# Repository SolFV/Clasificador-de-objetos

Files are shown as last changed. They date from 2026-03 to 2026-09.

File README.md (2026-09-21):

# 🏭 Clasificador Automático de Cajas con Visión Artificial
### Proyecto 4: Interfaz de Usuario y Estructura Mecánica de Cinta Transportadora

<div align="center">








**Sistema mecatrónico embebido de inspección de calidad y clasificación automatizada de paquetes sobre cinta transportadora, integrando visión artificial en la nube, tracción controlada por motor paso a paso, almacenamiento de evidencias y dashboard de supervisión en tiempo real.**

*Facultad de Ingeniería — Universidad Nacional de Asunción (FIUNA)*  
*Cátedra: Proyecto 4 (2do Ciclo 2026) | Septiembre de 2026*  
*Profesores: Prof. Ing. Federico Gaona, MSc. (Teoría) — Prof. Ing. Esteban Fretes, MSc. (Práctica)*

</div>

---

## 📋 Tabla de Contenidos

- [Descripción General](#-descripción-general)
- [Estado del Proyecto — Hitos del 1er Parcial](#-estado-del-proyecto--hitos-del-1er-parcial)
- [Esquema General del Sistema](#-esquema-general-del-sistema)
- [Arquitectura de Hardware](#️-arquitectura-de-hardware)
  - [1. Subsistema Mecánico y Estructura (SolidWorks)](#1-subsistema-mecánico-y-estructura-solidworks)
  - [2. Subsistema de Tracción (NEMA 23 + L298N)](#2-subsistema-de-tracción-nema-23--l298n)
  - [3. Subsistema Electrónico de Control (PCB ESP32-S3)](#3-subsistema-electrónico-de-control-pcb-esp32-s3)
- [Flujo de Operación y Lógica de Clasificación](#-flujo-de-operación-y-lógica-de-clasificación)
- [Infraestructura IoT y Servidor de Visión (n8n)](#-infraestructura-iot-y-servidor-de-visión-n8n)
- [Interfaz de Usuario (Dashboard de Supervisión)](#-interfaz-de-usuario-dashboard-de-supervisión)
- [Resultados Experimentales del Parcial](#-resultados-experimentales-del-parcial)
- [Costos del Proyecto](#-costos-del-proyecto)
- [Estructura del Repositorio](#-estructura-del-repositorio)
- [Autores y Agradecimientos](#-autores-fiuna--2026)
- [Licencia](#-licencia)

---

## 📖 Descripción General

El proyecto resuelve el **control de calidad en líneas de empaquetado** mediante un prototipo mecatrónico accesible y modular: una cinta transportadora desplaza cajas frente a una estación de inspección óptica (sensor infrarrojo de proximidad y cámara digital), un agente de visión artificial dictamina el estado del empaque y el sistema registra la evidencia fotográfica en la nube a la vez que acciona un mecanismo deflector para separar los productos defectuosos.

El alcance del **Primer Parcial del Proyecto 4** cierra la brecha entre la electrónica fabricada previamente en el Proyecto 3 y la operación física en planta, dotando al clasificador de:
1. **Estructura mecánica formal:** Chasis, rodillos, banda de caucho y soportes diseñados en SolidWorks con planos constructivos acotados.
2. **Tracción precisa con motor paso a paso:** Sustitución del motor DC de tracción por un motor paso a paso **NEMA 23** con controlador dedicado **L298N**, logrando un avance controlado con paradas repetibles de **1,2 s** frente a la cámara para eliminar el desenfoque por movimiento (*motion blur*).
3. **Pipeline de visión en la nube:** Servidor autoalojado **n8n** que procesa la imagen con **OpenAI `gpt-4o-mini`**, almacena evidencias en **Google Drive** y registros numéricos en **Google Sheets**.
4. **Dashboard web en tiempo real:** Interfaz de supervisión que lee la hoja de resultados cada 10 segundos, mostrando métricas, miniaturas de las cajas inspeccionadas y exportación a CSV.

---

## ✅ Estado del Proyecto — Hitos del 1er Parcial

> **El Primer Parcial del Proyecto 4 ha sido completado y validado experimentalmente con éxito en laboratorio.**

### Matriz de Hitos (P4 — Primer Parcial):

| Hito / Entregable | Estado | Observación |
| :--- | :---: | :--- |
| **Diseño mecánico en SolidWorks (CAD 3D)** | ✅ Completado | Modelos de bastidor, rodillos, engranajes y ensamble completo (`Ensamble.SLDASM`). |
| **Planos técnicos acotados de fabricación** | ✅ Completado | Planos 2D en PDF de engranaje conductor, conducido, soporte lateral y ensamble general. |
| **Tracción paso a paso NEMA 23 + L298N** | ✅ Completado | Paradas programadas de 1,2 s y avance exacto sin deslizamiento. |
| **Transmisión por engranajes rectos (3.8:1)** | ✅ Completado | Impresión 3D en PLA de piñón (z=10) y corona (z=38), módulo 4 mm. |
| **Flujo de Visión n8n + GPT-4o-mini** | ✅ Completado | Inferencia visual remota con latencia de 2,5 a 4,0 s. |
| **Registro Cloud (Google Drive + Sheets)** | ✅ Completado | Almacenamiento automático de fotos y fila de metadatos por evento. |
| **Dashboard Web de Supervisión** | ✅ Completado | Actualización continua cada 10 s, KPIs por estado, visor fotográfico y exportación CSV. |
| **Ensamble y validación del prototipo físico** | ✅ Completado | Estructura de contrachapado y varillas DIN 975 operativa y verificada en banco. |

---

## 🗺️ Esquema General del Sistema

El sistema opera mediante la interacción coordinada de cinco bloques funcionales:

```
                  +-------------------------------------------------------------+
                  |                      UNIDAD DE CONTROL                      |
                  |                Placa Propia ESP32-S3 (3.3V)                 |
                  +--------------+------------------------------+---------------+
                                 |                              |
               Señal de Detención|                              |Control de Desvío
               y Pulsos de Avance|                              |Pulsos PWM (0° / 180°)
                                 v                              v
            +--------------------+---------+          +---------+--------------------+
            |      SUBSISTEMA TRACCIÓN     |          |       SUBSISTEMA DESVÍO      |
            |     Driver L298N + NEMA 23   |          |    Servomotor SER0006        |
            |  Engranajes PLA (Red. 3.8:1) |          | Brazo Deflector (20s retenc.)|
            +--------------------+---------+          +------------------------------+
                                 |
                                 v
                     [ Cinta Transportadora ] <=== [ Cajas en Tránsito ]
                                 |
                          Detección IR (E18-D80NK)
                          Captura Foto (OV5640 SVGA)
                                 |
                                 v WiFi (HTTP POST Webhook)
            +--------------------+---------------------------------------------------+
            |                     SERVIDOR DE VISIÓN (n8n Autoalojado)               |
            |             Agente IA de Visión (OpenAI gpt-4o-mini)                  |
            +--------------------+------------------------------+--------------------+
                                 |                              |
                   Guarda Foto   v                 Guarda Fila  v
                         +-------+-------+              +-------+-------+
                         | Google Drive  |              | Google Sheets |
                         +-------+-------+              +-------+-------+
                                 |                              |
                                 |            Lectura cada 10 s |
                                 +--------------+---------------+
                                                v
                                 +--------------+---------------+
                                 |     DASHBOARD WEB (GUI)      |
                                 |  Supervisión en Tiempo Real  |
                                 +------------------------------+
```

---

## 🛠️ Arquitectura de Hardware

### 1. Subsistema Mecánico y Estructura (SolidWorks)
La cinta transportadora se diseñó íntegramente en SolidWorks bajo criterios de rigidez, repetibilidad y desmontaje modular:
- **Bastidor Lateral (`Tabla.SLDPRT` / [Soporte Lateral.pdf](Hardware/Diseno_Mecanico/Soporte%20Lateral.pdf)):** 2 placas de madera contrachapada de $700 \times 150\text{ mm}$ y $12\text{ mm}$ de espesor con perforaciones para varillas y rodamientos.
- **Tirantes Transversales (`Varilla.SLDPRT`):** 7 varillas roscadas de acero al carbono galvanizado bajo norma **DIN 975** (M6), aportando alta rigidez torsional.
- **Banda de Transporte (`Cinta.SLDPRT`):** Banda cerrada de caucho continuo con ancho útil de **200 mm**, compatible con cajas de hasta 150 mm.
- **Transmisión por Engranajes Rectos en PLA (Módulo 4 mm):**
  - **Engranaje Conductor (`Engranaje_C.SLDPRT` / [Engranaje_Conductor.pdf](Hardware/Diseno_Mecanico/Engranaje_Conductor.pdf)):** $z_1 = 10\text{ dientes}$, diámetro exterior $\varnothing 48.00\text{ mm}$, acople a eje del motor NEMA 23 de $\varnothing 8.00\text{ mm}$.
  - **Engranaje Conducido (`engranaje_G.SLDPRT` / [engranaje_conducido.PDF](Hardware/Diseno_Mecanico/engranaje_conducido.PDF)):** $z_2 = 38\text{ dientes}$, diámetro exterior $\varnothing 160.00\text{ mm}$, acople a eje motriz de $\varnothing 6.00\text{ mm}$.
  - **Relación de Reducción:** $i = 3.8:1$, cuadruplicando el par sobre el rodillo motriz y permitiendo una resolución de avance lineal de $\approx 0.165\text{ mm/paso}$.
- **Planos Técnicos:** Disponibles en [Hardware/Diseno_Mecanico/](Hardware/Diseno_Mecanico/) con el ensamble general en [Cinta transportadora.pdf](Hardware/Diseno_Mecanico/Cinta%20transportadora.pdf) y el informe técnico detallado en [Informe_Diseno_Estructural_Mecanico.md](Hardware/Diseno_Mecanico/Informe_Diseno_Estructural_Mecanico.md).

### 2. Subsistema de Tracción (NEMA 23 + L298N)
- **Motor:** Paso a paso híbrido bipolar NEMA 23 (**modelo 23HS5628**), ángulo de paso $1.8^\circ$ (200 pasos/rev) y torque nominal de **12.6 kgf-cm** (1.23 N·m).
- **Controlador:** Driver tipo puente H bipolar **L298N**, alimentado desde una línea de potencia externa dedicada y comandado por señales lógicas de 3.3V desde la placa ESP32-S3.

### 3. Subsistema Electrónico de Control (PCB ESP32-S3)
Se reutiliza la placa desarrollada y validada en el Proyecto 3 (alojada en [Hardware/Diseño final p3/](Hardware/Diseño%20final%20p3/)):
- **Microcontrolador:** ESP32-S3-WROOM-1-N16R8 (Dual-core 240 MHz, 16 MB Flash, 8 MB PSRAM verificada).
- **Cámara Óptica:** Módulo digital Omnivision **OV5640** conectado mediante interfaz de video en paralelo DVP (resolución de trabajo SVGA $800 \times 600$).
- **Sensor de Presencia:** Sensor fotoeléctrico infrarrojo **E18-D80NK** enfocado a la zona de captura (tiempo de respuesta $< 50\text{ ms}$).
- **Actuador de Desvío:** Servomotor **DFRobot SER0006** montado con brazo deflector mecánico a la salida del tramo de inspección.

---

## 🔄 Flujo de Operación y Lógica de Clasificación

El lazo de control opera de acuerdo a la siguiente secuencia automática:

1. **Avance Continuo:** El motor NEMA 23 hace avanzar la cinta transportadora de manera uniforme.
2. **Detección Frontal:** El sensor infrarrojo E18-D80NK detecta la llegada del paquete e interrumpe el avance.
3. **Parada y Captura:** La cinta se detiene exactamente durante **1,2 segundos**. La cámara OV5640 toma una fotografía nítida en SVGA almacenándola en la PSRAM.
4. **Transmisión IoT:** El ESP32-S3 envía la imagen por WiFi al webhook de n8n mediante HTTP POST.
5. **Inferencia Visual:** El agente de IA (`gpt-4o-mini`) analiza la morfología y condiciones del empaque, dictaminando la categoría:
   - 🟢 **Verde (Buen Estado):** Caja intacta, correctamente sellada y lista para despacho.
   - 🟡 **Amarillo (Sin Caja o No Empaque):** Falsa alarma, objeto extraño o cinta vacía.
   - 🔴 **Rojo (Caja Dañada):** Paquete aplastado, roto, perforado o con defectos visibles.
6. **Almacenamiento Cloud:** El flujo guarda la imagen en una carpeta compartida de **Google Drive** y registra una nueva fila en **Google Sheets** con timestamp, color y descripción detallada.
7. **Acción del Servomotor:** El ESP32-S3 recibe la respuesta `[{color, descripcion}]` y ejecuta la maniobra:
   - 🟢 **Verde:** El brazo deflector permanece a **0°** (la caja continúa sin desvío).
   - 🟡 / 🔴 **Amarillo o Rojo:** El servomotor gira a **180°** y mantiene la posición de desvío durante **20 segundos** para enviar la pieza a la bandeja de rechazo.
8. **Reanudación:** El servomotor retorna a posición neutra (0°) y la cinta reanuda la marcha.

---

## 🤖 Infraestructura IoT y Servidor de Visión (n8n)

El procesamiento cognitivo se delega íntegramente a un servidor local **n8n autoalojado** (*Workflow Proyecto 4*):

```
[Webhook HTTP] ──▶ [Recibir imagen y Nombrar] ──▶ [Base64 a Binario] ──▶ [AI Agent (gpt-4o-mini)]
                                                                                │
[Responder al Webhook: {color, desc}] ◀── [Limpiar Output Agente] ◀─────────────┘
          │
          ├──▶ [Subir a Google Drive]
          └──▶ [Subir a Google Sheets]
```

- **Modelo de Inferencia:** OpenAI `gpt-4o-mini` configurado con *system prompt* especializado en control de calidad industrial.
- **Respuesta JSON:** Formato estandarizado `[ { "color": "verde" | "amarillo" | "rojo", "descripcion": "..." } ]`.
- **Ventaja de la Arquitectura:** Libera al microcontrolador de tareas pesadas de redes neuronales, acelerando la toma de decisiones ($2.5 - 4.0\text{ s}$).

---

## 🖥️ Interfaz de Usuario (Dashboard de Supervisión)

El monitoreo del sistema se realiza a través de un **Dashboard Web en Tiempo Real** de un solo archivo:
- **Consulta Automática:** Sondea la planilla de Google Sheets (*Proyecto4 - Hoja 1*) cada **10 segundos**.
- **Panel de KPIs:** Conteo total de cajas evaluadas, desglose por categoría (verde, amarillo, rojo) y cálculo porcentual.
- **Tarjeta de Última Detección:** Muestra la fotografía en miniatura cargada desde Google Drive, el estado asignado, la descripción diagnóstica de la IA y el ángulo/tiempo aplicado por el servomotor.
- **Historial y Exportación:** Tabla con las últimas 5 detecciones en vivo y botón para exportar todo el registro histórico acumulado a formato **CSV**.
- **Accesos Directos:** Enlaces directos a la planilla en línea y a la carpeta de evidencias en Drive.
- **Modo Seguro:** Opera en modo solo lectura para supervisión remota sin interferir en la máquina de estados del firmware.

---

## 📊 Resultados Experimentales del Parcial

Durante las pruebas funcionales del prototipo integrado se validaron las siguientes métricas de desempeño:

| Parámetro Operativo | Valor Medido | Valor Esperado / Criterio |
| :--- | :---: | :---: |
| **Tiempo de parada de cinta frente a cámara** | **1,2 s** | Repetible, sin desenfoque de imagen |
| **Latencia de detección del sensor IR** | **< 50 ms** | Detención instantánea del NEMA 23 |
| **Tiempo de respuesta inferencia n8n** | **2,5 a 4,0 s** | Dentro del ciclo de cinta previsto |
| **Retención del servomotor en rechazo (180°)** | **20 s** | Desvío seguro al contenedor de descarte |
| **Frecuencia de actualización del Dashboard** | **10 s** | Supervisión fluida de métricas Cloud |
| **Resolución cinemática de la cinta** | **~0,165 mm/paso** | Posicionamiento milimétrico repetible |

---

## 💰 Costos del Proyecto

La estructura de costos del prototipo se basa en una tasa oficial de referencia de **1 USD = 6.391 Gs.**:

### 1. Materiales y Herramientas Compradas (Incorporadas al Proyecto 4)

| Descripción / Componente | MPN / Modelo | Cant. | Unitario (USD) | Total (USD) | Total (Gs.) |
| :--- | :--- | :---: | :---: | :---: | :---: |
| **Motor paso a paso NEMA 23 (12.6 kgf-cm)** | 23HS5628 | 1 | 46,94 | 46,94 | 300.000 |
| **Microcontrolador ESP32-S3** | ESP32-S3-WROOM-1-N16R8 | 2 | 8,72 | 17,44 | 111.459 |
| **Módulo de cámara OV5640** | 5840 (Adafruit) | 1 | 9,95 | 9,95 | 63.590 |
| **Capacitor electrolítico 100 uF** | EEE-FK1H101P | 6 | 0,76 | 4,56 | 29.143 |
| **Servomotor 180°** | SER0006 | 1 | 3,63 | 3,63 | 23.199 |
| **Capacitor cerámico 4,7 uF 0805** | CL21B475KOFNNNE | 6 | 0,25 | 1,50 | 9.587 |
| **Diodo Schottky 40 V, 1 A** | SS14F-HF | 4 | 0,32 | 1,28 | 8.180 |
| **Conector USB tipo C hembra** | USB4510-03-1-A | 1 | 0,84 | 0,84 | 5.368 |
| **Capacitor cerámico 10 uF 0805** | CL21B106KOQNNNE | 6 | 0,14 | 0,84 | 5.368 |
| **Capacitor cerámico 22 uF 0805** | CL21A226MQQNNNE | 6 | 0,13 | 0,78 | 4.985 |
| **Resistencia 15 kOhm 0805** | RC0805FR-0715KL | 6 | 0,13 | 0,78 | 4.985 |
| **Capacitor cerámico 2,2 uF 0805** | CL21B225KOFNNNE | 6 | 0,12 | 0,72 | 4.602 |
| **Regulador LDO 3,3 V** | LD1117S33TR | 2 | 0,34 | 0,68 | 4.346 |
| **Resistencia 10 kOhm 0805** | RC0805FR-0710KL | 6 | 0,11 | 0,66 | 4.218 |
| **Capacitores y Resistencias SMD 0805 varios** | Pasivos estándar | — | — | 6,14 | 39.299 |
| **SUBTOTAL COMPONENTES COMPRADOS** | — | — | — | **$96,06** | **644.219 Gs.** |

> *Costo por integrante (3 personas): **$32.02 USD (214.740 Gs.)**.*  
> El desglose línea a línea con enlaces y números de parte se encuentra en el archivo [BOM.csv](BOM.csv).

### 2. Materiales y Herramientas Preexistentes o Prestadas (Sin costo incremental)

| Descripción | Cantidad | Observaciones / Procedencia |
| :--- | :---: | :--- |
| **Placa propia ESP32-S3 con cámara OV5640** | 1 | Fabricada y validada en Proyecto 3 |
| **Servomotor de desvío SER0006** | 1 | Reutilizado de la etapa previa |
| **Controlador L298N para motor paso a paso** | 1 | Driver provisto para tracción |
| **Notebook con servidor n8n autoalojado** | 1 | Estación de inferencia local |
| **Licencia / estación SolidWorks CAD** | 1 | Laboratorio FIUNA |
| **Multímetro y herramientas de banco/taller** | 1 | Instrumental de ensamblaje y prueba |

---

## 📁 Estructura del Repositorio

```
📦 Clasificador de Objetos/
├── 📂 Hardware/                                # Proyectos de diseño físico y electrónico
│   ├── 📂 Diseno_Mecanico/                     # Diseño mecánico CAD y planos (P4)
│   │   ├── 📄 Informe_Diseno_Estructural_Mecanico.md # Informe técnico mecánico detallado
│   │   ├── 📄 Cinta transportadora.pdf         # Plano de ensamble general, despiece y lista de partes
│   │   ├── 📄 Soporte Lateral.pdf              # Plano acotado de soporte lateral de madera contrachapada
│   │   ├── 📄 Engranaje_Conductor.pdf          # Plano acotado de engranaje conductor (z=10, m=4)
│   │   ├── 📄 engranaje_conducido.PDF          # Plano acotado de engranaje conducido (z=38, m=4)
│   │   ├── 🧊 Ensamble.SLDASM                  # Ensamblaje 3D general en SolidWorks
│   │   ├── 🧊 Cinta.SLDPRT                     # Modelo 3D de la banda transportadora
│   │   ├── 🧊 Engranaje_C.SLDPRT               # Modelo 3D de engranaje conductor (PLA)
│   │   ├── 🧊 engranaje_G.SLDPRT               # Modelo 3D de engranaje conducido (PLA)
│   │   ├── 🧊 Tabla.SLDPRT                     # Modelo 3D de soporte lateral
│   │   ├── 🧊 Varilla.SLDPRT                   # Modelo 3D de varilla roscada DIN 975
│   │   └── 🧊 nema23.SLDPRT                    # Modelo 3D de motor paso a paso NEMA 23
│   ├── 📂 Componentes/                         # Bibliotecas KiCad personalizadas
│   ├── 📂 Diseño final p3/                     # Proyecto final KiCad de la PCB (Proyecto 3)
│   │   └── 📂 Grupo15/                         # Esquemático, ruteado, producción y Gerbers
│   ├── 📂 ESP32_S3_WROOM2_N32R16_29/           # Footprint y símbolo de la MCU
│   ├── 🖼️ Diseño.jpeg                          # Esquemático general del circuito
│   ├── 🖼️ pcb_ruteado.PNG                       # Ruteado y layout de 2 capas
│   ├── 🖼️ pcb_3d.PNG                           # Render 3D superior de la PCB
│   ├── 🖼️ pcb_3d_1.png                         # Render 3D superior sin componentes
│   └── 🖼️ pcb_3d_vistinferior.png              # Render 3D inferior de la PCB
├── 📂 Software/                                # Firmware y aplicaciones de control
│   ├── 📄 P3_2P_code.txt                       # Firmware C++/Arduino para ESP32-S3
│   ├── 📂 SnapshotP4.0/                        # Aplicación Android para inspección
│   │   └── 📱 Cinta IA.apk                     # Instalador ejecutable Android
│   └── 📂 Pruebas/                             # Scripts de validación de cámara y PSRAM
├── 📄 BOM.csv                                  # Lista de materiales y costos actualizada (USD / Gs.)
├── 📄 Informe_finalP3.pdf                      # Informe oficial completo del Proyecto 3
├── 📄 Cronograma de actividades P4.pdf         # Cronograma oficial de la Etapa P4 (PDF)
├── 📊 Cronograma de actividades.xlsx           # Planilla Excel de seguimiento
├── 🖼️ DiagramadeGantt.png                     # Diagrama de Gantt oficial
├── 🖼️ diagrama-flujo.png                       # Diagrama de flujo general del sistema
├── 📄 LICENSE                                  # Licencia de código abierto MIT
└── 📄 README.md                                # Documentación principal del repositorio
```

---

## 👥 Autores (FIUNA — 2026)

* **José Fabián Medina Dávalos** — [jfmedina@fiuna.edu.py](mailto:jfmedina@fiuna.edu.py)
* **Sol Aramí Fernández Vargas** — [solfernandez@fiuna.edu.py](mailto:solfernandez@fiuna.edu.py)
* **Gabriela Belén Orrego Arzamendia** — [gorrego@fiuna.edu.py](mailto:gorrego@fiuna.edu.py)

**Facultad de Ingeniería — Universidad Nacional de Asunción (FIUNA)**  
*Cátedra de Proyecto 4 — Carrera de Ingeniería Mecatrónica*  
*Docentes:* Prof. Ing. Federico Gaona, MSc. (Teoría) & Prof. Ing. Esteban Fretes, MSc. (Práctica)

---

## 📄 Licencia

Este proyecto está distribuido bajo la **Licencia MIT**. Para más detalles, consulte el archivo [LICENSE](LICENSE).

---

<div align="center">

*Clasificador Automático de Cajas con Visión Artificial — FIUNA — 2026*

</div>

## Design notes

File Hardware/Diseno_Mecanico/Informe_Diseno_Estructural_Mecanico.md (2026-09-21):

# 📐 Informe Técnico: Diseño Estructural y Mecánico de la Cinta Transportadora
**Proyecto 4 — Clasificador Automático de Cajas con Visión Artificial: Interfaz de Usuario y Estructura Mecánica de Cinta Transportadora**  
*Facultad de Ingeniería — Universidad Nacional de Asunción (FIUNA)*  
*Cátedra: Proyecto 4 (2do Ciclo 2026) | Profesores: Prof. Ing. Federico Gaona, MSc. — Prof. Ing. Esteban Fretes, MSc.*  
*Autores: José Fabián Medina Dávalos, Sol Aramí Fernández Vargas, Gabriela Belén Orrego Arzamendia*

---

## 1. 📌 Descripción General y Alcance del Diseño Mecánico

El presente informe técnico describe la arquitectura estructural, componentes de ensamble, cálculos cinemáticos y planos de fabricación del sistema mecánico de la cinta transportadora del **Proyecto 4 (Primer Parcial)**.

En esta etapa, el sistema sustituye el accionamiento previo por motor DC por un **motor paso a paso NEMA 23 (23HS5628)** acoplado mediante un par de engranajes rectos de reducción diseñados en **SolidWorks**. Esta solución garantiza un avance controlado, repetible y con paradas programadas de **1,2 s** frente a la estación de inspección óptica (cámara OV5640 y sensor infrarrojo E18-D80NK), suprimiendo cualquier desenfoque por movimiento (*motion blur*) durante la captura de imágenes.

```
+-----------------------------------------------------------------------------------------+
|                                ESTRUCTURA MECÁNICA GENERAL                              |
|                                                                                         |
|  [ Motor NEMA 23 ]                                                                      |
|        |                                                                                |
|  [ Engranaje Conductor (z=10, m=4) ]                                                    |
|        | (Reducción 3.8:1)                                                              |
|  [ Engranaje Conducido (z=38, m=4) ]                                                    |
|        |                                                                                |
|  [ Eje y Rodillo Motriz ] ======> [ Banda de Caucho (200 mm) ] ======> [ Rodillo Tensor ]
|                                    (Chasis: Madera Contrachapada + 7 Varillas DIN 975)  |
+-----------------------------------------------------------------------------------------+
```

---

## 2. ⚙️ Criterios de Diseño y Requerimientos Funcionales

1. **Ancho Útil de Transporte:** Banda de $200\text{ mm}$ de ancho para alojar con holgura paquetes y cajas de hasta $150\text{ mm}$.
2. **Control de Avance y Posicionamiento:** Capacidad de detener la cinta de manera instantánea y repetible al activarse el sensor IR E18-D80NK (latencia $< 50\text{ ms}$).
3. **Rigidez Torsional y Alineación:** Chasis autoportante de madera contrachapada fijado mediante varillas roscadas pasantes de acero métrico, garantizando paralelismo estricto entre ejes.
4. **Mantenimiento y Desmontaje:** Facilidad para cambiar o tensar la banda sin requerir el desarmado total del bastidor.
5. **Manufactura Híbrida y Accesible:**
   - Estructura portante en madera contrachapada mecanizada.
   - Transmisión cinemática fabricada mediante **impresión 3D (PLA)**.
   - Elementos de unión normalizados (acero DIN 975 grado comercial).

---

## 3. 🧩 Descripción de Componentes Mecánicos

### 3.1 Chasis y Laterales del Bastidor (`Tabla.SLDPRT` / `Soporte Lateral.pdf`)
- **Material:** Madera contrachapada de primera calidad de $12.00\text{ mm}$ de espesor.
- **Dimensiones Principales:** Longitud total $700.00\text{ mm}$, altura $150.00\text{ mm}$.
- **Puntos de Sujeción y Fijación:**
  - 6 perforaciones pasantes de $\varnothing 6.50\text{ mm}$ distribuidas a lo largo del soporte para las varillas roscadas estructurales (con cotas de espaciado $175.00\text{ mm}$, $350.00\text{ mm}$, etc.).
  - Alojamiento de ejes principales con orificios de $\varnothing 8.00\text{ mm}$ situados a $25.00\text{ mm}$ y $58.04\text{ mm}$ de referencias clave.
  - Guías y ranuras de ajuste para el tensado de la banda en el rodillo conducido.

### 3.2 Tirantes Estructurales Transversales (`Varilla.SLDPRT`)
- **Norma y Material:** Acero al carbono galvanizado según norma **DIN 975**.
- **Cantidad:** 7 varillas roscadas M6.
- **Función:** Unen rígidamente ambos laterales de madera contrachapada mediante tuercas y arandelas exteriores e interiores, proporcionando una estructura tipo celosía de alta resistencia a la flexión y torsión.

### 3.3 Banda Transportadora y Rodillos (`Cinta.SLDPRT`)
- **Banda:** Banda plana vulcanizada de caucho continuo con cara superior antideslizante de $200\text{ mm}$ de ancho útil.
- **Rodillos:** Cilindros concéntricos montados sobre rodamientos de bolas de bajo rozamiento para asegurar rotación suave bajo carga.

---

## 4. ⚙️ Sistema de Transmisión por Engranajes Cilíndricos Rectos

Para vincular el motor NEMA 23 al eje del rodillo motriz se diseñó una etapa reductora de engranajes de dientes rectos, modelados en SolidWorks e impresos en PLA de alta densidad de relleno.

### 4.1 Parámetros Geométricos del Engranaje Conductor (`Engranaje_C.SLDPRT` / `Engranaje_Conductor.pdf`)

| Parámetro Geométrico | Símbolo | Valor de Diseño |
| :--- | :---: | :---: |
| **Módulo** | $m$ | $4\text{ mm}$ |
| **Número de Dientes** | $z_1$ | $10$ |
| **Ángulo de Presión** | $\alpha$ | $20^\circ$ |
| **Diámetro Primitivo** | $d_{p1} = m \cdot z_1$ | $40.00\text{ mm}$ |
| **Diámetro Exterior** | $d_{e1} = d_{p1} + 2m$ | $48.00\text{ mm}$ |
| **Espesor del Diente (Ancho de Cara)** | $b_1$ | $12.00\text{ mm}$ |
| **Altura Total con Cubo** | $h_{\text{cubo}}$ | $22.00\text{ mm}$ |
| **Diámetro del Cubo** | $d_{\text{cubo}}$ | $16.00\text{ mm}$ |
| **Diámetro de Eje (Eje Motor NEMA 23)** | $d_{\text{eje1}}$ | $\varnothing 8.00\text{ mm}$ |
| **Tipo de Perfil** | — | Evolvente / Involuta estándar |
| **Material** | — | Polímero termoplástico (PLA) |

### 4.2 Parámetros Geométricos del Engranaje Conducido (`engranaje_G.SLDPRT` / `engranaje_conducido.PDF`)

| Parámetro Geométrico | Símbolo | Valor de Diseño |
| :--- | :---: | :---: |
| **Módulo** | $m$ | $4\text{ mm}$ |
| **Número de Dientes** | $z_2$ | $38$ |
| **Ángulo de Presión** | $\alpha$ | $20^\circ$ |
| **Diámetro Primitivo** | $d_{p2} = m \cdot z_2$ | $152.00\text{ mm}$ |
| **Diámetro Exterior** | $d_{e2} = d_{p2} + 2m$ | $160.00\text{ mm}$ |
| **Espesor del Diente** | $b_2$ | $12.00\text{ mm}$ |
| **Diámetro de Eje** | $d_{\text{eje2}}$ | $\varnothing 6.00\text{ mm}$ |
| **Tipo de Perfil** | — | Evolvente / Involuta estándar |
| **Material** | — | Polímero termoplástico (PLA) |

### 4.3 Relación de Reducción y Distancia Entre Centros

* **Relación de transmisión ($i$):**
  $$i = \frac{z_2}{z_1} = \frac{38}{10} = 3.8:1$$

* **Distancia teórica entre centros ($a$):**
  $$a = \frac{d_{p1} + d_{p2}}{2} = \frac{40\text{ mm} + 152\text{ mm}}{2} = \frac{192\text{ mm}}{2} = 96.00\text{ mm}$$

> **Efecto cinemático:** La relación de reducción $3.8:1$ multiplica el torque entregado al rodillo motriz por un factor de casi 4, permitiendo mover la cinta con suavidad y posicionar la caja de manera controlada frente a la cámara.

---

## 5. 🧮 Cinemática de Tracción y Parada

### 5.1 Motor Paso a Paso NEMA 23 (Modelo 23HS5628)
- **Ángulo de paso nativo:** $1.8^\circ \pm 5\%$ ($200\text{ pasos/revolución}$).
- **Torque de retención nominal:** $12.6\text{ kgf}\cdot\text{cm}$ ($1.23\text{ N}\cdot\text{m}$).
- **Controlador:** L298N (puente H bipolar).

### 5.2 Desplazamiento Lineal por Paso
Para un diámetro del rodillo motriz $D_{\text{rodillo}} \approx 40\text{ mm}$:
- Circunferencia del rodillo motriz:
  $$C_{\text{rodillo}} = \pi \cdot D_{\text{rodillo}} \approx 3.1416 \times 40\text{ mm} \approx 125.66\text{ mm}$$
- Desplazamiento lineal del rodillo motriz por revolución del motor:
  $$\Delta x_{\text{rev\_motor}} = \frac{C_{\text{rodillo}}}{i} = \frac{125.66\text{ mm}}{3.8} \approx 33.07\text{ mm/rev}$$
- Resolución de avance por paso del motor ($1.8^\circ$):
  $$\Delta x_{\text{paso}} = \frac{33.07\text{ mm}}{200\text{ pasos}} \approx 0.165\text{ mm/paso}$$

Esta precisión milimétrica ($0.165\text{ mm}$ por paso completo) garantiza que cuando el sensor fotoeléctrico infrarrojo **E18-D80NK** detecta el borde de ataque de la caja, la cinta se detiene exactamente en el centro del encuadre óptico de la cámara **OV5640**.

---

## 6. 📋 Lista de Partes y Ensamble General (`Ensamble.SLDASM` / `Cinta transportadora.pdf`)

| Ítem | N° de Parte / Nombre | Descripción y Material | Cantidad | Plano Técnico / Modelo |
| :---: | :--- | :--- | :---: | :--- |
| **1** | `Soporte Lateral` | Madera Contrachapada e = 12 mm | 2 | `Soporte Lateral.pdf` / `Tabla.SLDPRT` |
| **2** | `Varilla Roscada` | Acero al carbono DIN 975 M6 | 7 | `Varilla.SLDPRT` |
| **3** | `Motor Paso a Paso` | NEMA 23 (23HS5628) | 1 | `nema23.SLDPRT` |
| **4** | `Engranaje Conducido` | Polímero (PLA) z=38, m=4 | 1 | `engranaje_conducido.PDF` / `engranaje_G.SLDPRT` |
| **5** | `Engranaje Conductor` | Polímero (PLA) z=10, m=4 | 1 | `Engranaje_Conductor.pdf` / `Engranaje_C.SLDPRT` |
| **6** | `Cinta` | Banda cerrada de Caucho (200 mm útil) | 1 | `Cinta.SLDPRT` |
| **7** | `Ensamble General` | Conjunto montado de cinta transportadora | 1 | `Cinta transportadora.pdf` / `Ensamble.SLDASM` |

---

## 7. 📸 Registro Fotográfico del Prototipo Construido

Durante la fase de validación física del prototipo se registraron las siguientes observaciones de ensamble:
- **Estructura Portante:** Soportes de madera contrachapada alineados rígidamente por las 7 varillas roscadas de acero M6 con doble tuerca de apriete.
- **Montaje del Motor:** El NEMA 23 se encuentra asegurado firmemente al lateral de la cinta, con su eje de $\varnothing 8\text{ mm}$ acoplado al engranaje conductor de 10 dientes en PLA.
- **Engrane:** El engranaje conducido de 38 dientes engrana directamente con el conductor, verificándose un juego entre dientes (*backlash*) adecuado para evitar atoramientos y desgaste prematuro.
- **Respuesta Operativa:** Paradas programadas de **1,2 s** perfectamente repetibles y estables ante la detección por el sensor IR, sin deslizamiento apreciable de la banda de caucho.

---

## 8. 🎯 Conclusiones del Diseño Mecánico (1er Parcial)

1. La sustitución del motor DC por el motor paso a paso **NEMA 23** con transmisión de engranajes $3.8:1$ solucionó de raíz el problema de la inercia y la repetibilidad del frenado.
2. El uso de engranajes de módulo $m = 4\text{ mm}$ proporciona robustez suficiente ante los esfuerzos dinámicos de arranque y frenado brusco.
3. Como mejora para las siguientes fases se contempla incorporar un tensor dinámico con resorte para la banda de caucho y una cubierta protectora para los engranajes de transmisión.

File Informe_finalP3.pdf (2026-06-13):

Clasificador de Objetos - Informe Final de Proyecto | Medina, Fernández, Orrego

## Resumen Ejecutivo

El presente proyecto detalla el diseño, fabricación e implementación de una placa electrónica (PCB) basada en el microcontrolador ESP32-S3, destinada al control y supervisión de una cinta transportadora inteligente. El sistema tiene como propósito principal la clasificación automatizada de objetos integrando tecnologías de visión artificial e Internet de las Cosas (IoT). A través de un módulo de cámara, el hardware captura imágenes de los elementos en la cinta y las transmite vía WiFi (mediante un webhook) a un servidor autoalojado de procesamiento, donde un algoritmo de inteligencia artificial evalúa si el objeto es correcto o defectuoso. Posteriormente, la PCB recibe la decisión del servidor y acciona un servomotor para desviar los elementos anómalos, mientras gestiona simultáneamente el encendido, apagado y la velocidad de un motor DC que impulsa la cinta transportadora.

En este documento se expone la metodología de diseño de hardware, el ruteo de la PCB separando etapas de potencia y señal, el ensamblaje, la lógica de programación del ESP32-S3 y las pruebas de validación de tiempos de respuesta y estabilidad de comunicación. Los resultados esperados apuntan a obtener un sistema de clasificación autónomo, eficiente y de baja latencia en entornos de automatización industrial.

## Abstract

This project details the design, manufacturing, and implementation of a printed circuit board (PCB) based on the ESP32-S3 microcontroller, intended for the control and supervision of a smart conveyor belt. The system's main purpose is the automated classification of objects by integrating machine vision and Internet of Things (IoT) technologies. Through a camera module, the hardware captures images of the items on the belt and transmits them via WiFi (using a webhook) to a self-hosted processing server, where an artificial intelligence algorithm evaluates whether the object is correct or defective. Subsequently, the PCB receives the server's decision and actuates a servomotor to divert anomalous items, while simultaneously managing the start, stop, and speed of a DC motor driving the conveyor belt.

This document presents the hardware design methodology, PCB routing (separating power and signal stages), assembly, ESP32-S3 programming logic, and validation tests regarding response times and communication stability. The expected results aim to achieve an autonomous, efficient, and low-latency classification system for industrial automation environments.

## Estado del Arte

El uso de microcontroladores de bajo costo combinados con visión artificial e Internet de las Cosas (IoT) ha revolucionado la automatización a pequeña y mediana escala. A continuación, se analizan cuatro trabajos recientes que fundamentan la viabilidad técnica de este proyecto:

[1] Y. C. et al., "Design and Implementation of a Low-Cost IoT-Based Robotic Arm for Product

Clasificador de Objetos - Informe Final de Proyecto | Medina, Fernández, Orrego

Feeding and Sorting in Manufacturing Lines," MDPI, vol. 14, 2024\.

- Análisis: Este artículo de la revista científica MDPI presenta un enfoque de Industria 5.0 utilizando el ESP32 como controlador de borde (Edge Controller) para automatizar una línea de producción. Los autores demuestran que el ESP32 es capaz de ejecutar proyectos de visión artificial con tasas de error competitivas, gestionando simultáneamente la comunicación IoT mediante Wi-Fi.
- Relación con el proyecto: Esta investigación respalda nuestra elección del ESP32-S3 como núcleo del sistema, validando su capacidad para manejar la concurrencia entre el procesamiento de datos visuales, el control de actuadores (cinta) y la transmisión de información a un servidor autoalojado sin sufrir cuellos de botella severos.
[2] M. S. et al., "Color based product sorting machine using embedded vision and IoT," Int. Journal of Novel Research and Development (IJNRD), 2024\.
- Análisis: En este trabajo se desarrolla una máquina clasificadora que utiliza un módulo de cámara embebido para analizar objetos en movimiento sobre una cinta transportadora. El hardware principal controla motores DC mediante un driver L298N para la tracción de la cinta y servomotores para desviar los productos a diferentes contenedores, enviando un registro de la clasificación a una plataforma en la nube vía Wi-Fi.
- Relación con el proyecto: El diseño de hardware expuesto en este documento es altamente análogo al nuestro. Confirma que la topología electrónica de separar la lógica de control (ESP32) de la etapa de potencia (driver de motor DC y servos de desvío) es el estándar adecuado para garantizar un flujo continuo en el proceso de descarte.
[3] L. Osés, B. Pezet, M. Salina, J. Osio, M. Cappelletti, y M. Morales, "Sistema de clasificación de objetos para un recolector de residuos inteligente mediante visión artificial y aprendizaje profundo," en 11° Congreso Nacional de Ingenierías en Informática y Sistemas de Información, 2023\.
- Análisis: Este trabajo de grado y ponencia en el congreso argentino JAIIO documenta la implementación de un sistema de recolección que utiliza una placa ESP32-CAM para capturar imágenes y transmitirlas a un servidor, donde una red neuronal evalúa los objetos para su posterior clasificación mecánica.
- Relación con el proyecto: Esta referencia es vital porque valida la arquitectura de software propuesta en nuestro proyecto: delegar la inferencia pesada (IA) a un servidor autoalojado comunicándose a través de solicitudes HTTP (webhooks). Demuestra que esta división de tareas reduce el consumo de recursos en el microcontrolador y acelera el tiempo de decisión.
[4] A. K. et al., "Development of Real-Time Crop Sorting System Based on Deep Learning and ESP32-CAM Integration," Scientific Research Publishing (SCIRP), 2024\.
- Análisis: Los investigadores diseñaron un sistema dinámico que integra una cinta transportadora motorizada, un mecanismo de control basado en microcontroladores y algoritmos de visión profunda (YOLO) para clasificar productos agrícolas en tiempo real según su estado. El sistema demostró una alta precisión en entornos dinámicos.
- Relación con el proyecto: Este artículo demuestra que los sistemas de captura basados en la familia ESP32 pueden lidiar con los problemas de desenfoque por movimiento (motion blur) inherentes a una

Clasificador de Objetos - Informe Final de Proyecto | Medina, Fernández, Orrego

cinta transportadora, justificando nuestra propuesta de evaluar rigurosamente los tiempos de respuesta (captura → envío → decisión → acción) para activar el servomotor en el milisegundo exacto.

Clasificador de Objetos - Informe Final de Proyecto | Medina, Fernández, Orrego

## Descripción del Proyecto

El proyecto propone la creación de un prototipo funcional para resolver problemas de control de calidad y automatización en líneas de ensamblaje o empaquetado. La motivación principal radica en la necesidad de democratizar el acceso a sistemas de clasificación industrial, reemplazando costosos equipos tradicionales por una arquitectura basada en el ESP32-S3, la cual ofrece un equilibrio ideal entre capacidad de procesamiento, conectividad WiFi nativa e integración con hardware de visión artificial a un bajo costo. El sistema enfocará sus esfuerzos en garantizar una comunicación fluida entre el hardware de borde (PCB) y el servidor de IA autoalojado, asegurando que la captura fotográfica, la inferencia y el desvío mecánico operen en una ventana de tiempo óptima para la continuidad del proceso.

### Estructura de Desglose del Producto (PBS)

Figura 1
Estructura de Desglose del Producto para el Sistema de Clasificación Inteligente

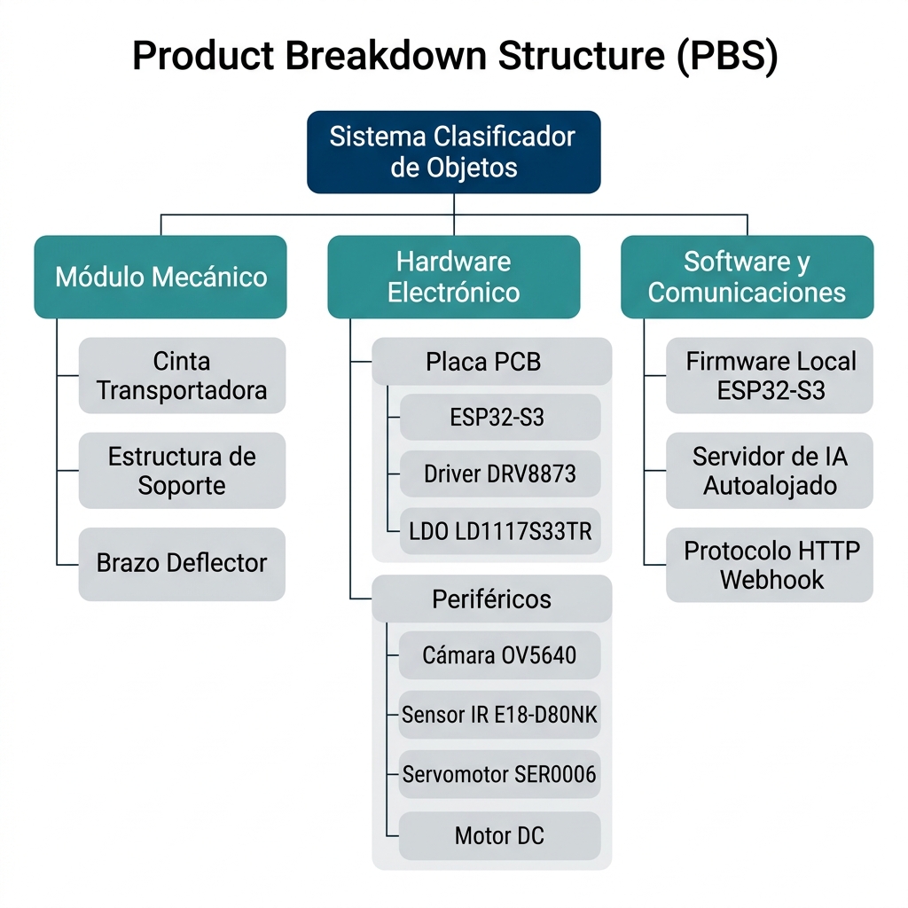
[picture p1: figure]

Estructura de Desglose del Producto

Clasificador de Objetos - Informe Final de Proyecto | Medina, Fernández, Orrego

Nota. El diagrama detalla la descomposición jerárquica del sistema en tres pilares principales: el módulo mecánico, el hardware electrónico y la arquitectura de software/comunicaciones, junto con sus respectivos subcomponentes.

Clasificador de Objetos - Informe Final de Proyecto | Medina, Fernández, Orrego

## Objetivos

### Objetivo General

Implementar un sistema de adquisición de imágenes para la supervisión, clasificación de objetos y control de una cinta transportadora.

### Objetivos Específicos

- Desarrollar una PCB propia para la captura de imágenes e interfaz física con el motor de la cinta transportadora.
- Construir el sistema físico integrando la placa electrónica y el sistema de captura de imágenes a la estructura de la cinta.
- Establecer la comunicación de datos para la transmisión remota de las imágenes obtenidas hacia un servidor de procesamiento autoalojado.
- Validar el desempeño del sistema evaluando la precisión en la clasificación de objetos, el tiempo de respuesta de la red y el correcto accionamiento de la cinta.

Clasificador de Objetos - Informe Final de Proyecto | Medina, Fernández, Orrego

## Esquema General del Proyecto

El sistema se compone de los siguientes bloques interconectados:

- Unidad de Control Central (ESP32-S3): Actúa como el núcleo de procesamiento local. Opera con niveles lógicos de 3.3V y gestiona tanto la adquisición de datos periféricos como el enlace de comunicación inalámbrica vía Wi-Fi con el servidor autoalojado de procesamiento.
- Sistema de Adquisición Óptica (Cámara OV5640): Módulo encargado de la captura de imágenes de alta definición. Se comunica directamente con el microcontrolador mediante una interfaz de video digital paralelo (DVP) para garantizar la velocidad de transferencia del buffer.
- Sistema de Tracción (Motor DC): Encargado de impulsar la cinta transportadora. Funciona acoplado a un driver de potencia y su velocidad de arrastre se regula mediante señales de modulación por ancho de pulsos (PWM) generadas por el firmware local.
- Mecanismo de Clasificación (Servomotor): Actuador responsable de accionar el brazo deflector para el desvío físico de los objetos. Se alimenta de forma independiente a 5V y responde a comandos PWM según la categoría asignada por el backend en el servidor autoalojado.
- Red de Distribución de Potencia: Compuesta por reguladores de tensión fijos (LDO y convertidores) que adaptan el voltaje de la fuente principal a las líneas estables de 3.3V, 5V y potencia requeridas por los componentes electrónicos y electromecánicos.

Figura 2
Arquitectura General y Diagrama de Bloques del Sistema Integrado

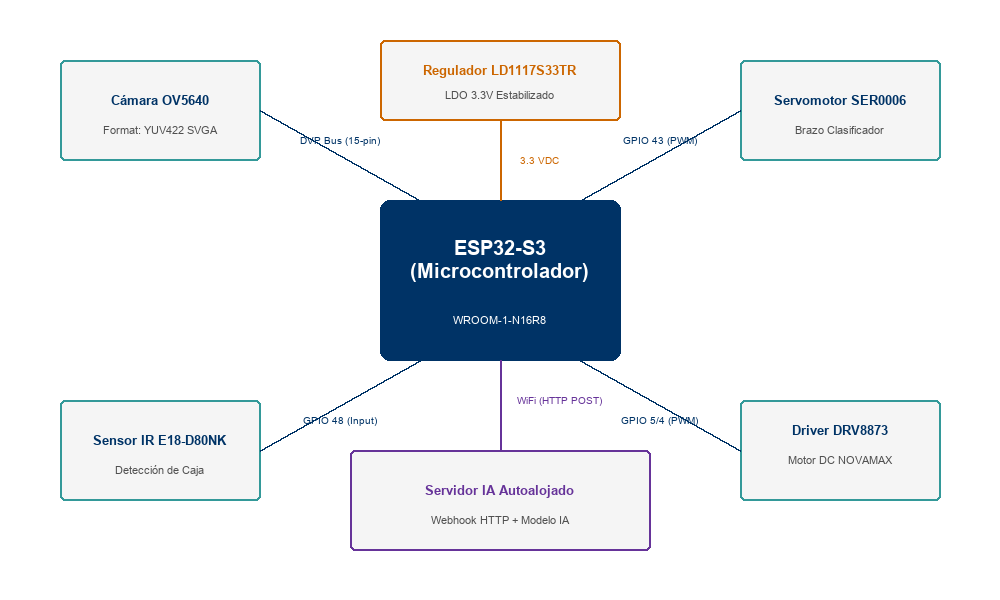
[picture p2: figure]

Arquitectura General y Diagrama de Bloques

Nota. El diagrama ilustra la interconexión funcional entre los módulos mecánicos, la tarjeta de control basada en el ESP32-S3 y la plataforma del servidor autoalojado, detallando las interfaces de comunicación y las etapas de potencia involucradas.

Clasificador de Objetos - Informe Final de Proyecto | Medina, Fernández, Orrego

## Diseños Electrónicos

### Descripción del Hardware

El diseño electrónico se fundamenta en la separación de las etapas de potencia y de control para evitar ruidos parásitos en la lógica del ESP32-S3. El esquema incluye un driver de potencia para modular la velocidad y encendido del motor DC mediante PWM. Se implementará un mapeo de pines (pinout) específico que dedique puertos de hardware exclusivos para la cámara, salidas PWM para el servo y el motor DC, y pines de monitoreo para supervisión. Las imágenes del esquemático, layout de la PCB y los planos generados se adjuntan en la sección de Anexos.

### Sistema de Control Aplicado

El proyecto implementa un sistema de control distribuido y basado en eventos. A nivel de arquitectura, utiliza un enfoque de control de borde (Edge Computing) mediante el ESP32-S3-WROOM-1-N16R8 para el manejo de hardware en tiempo real (motor DC y actuadores), mientras delega el procesamiento de imágenes y la toma de decisiones al servidor de procesamiento de IA autoalojado mediante IoT. La clasificación de objetos opera como un sistema de lazo cerrado, utilizando la cámara como sensor de retroalimentación visual para accionar el desvío mecánico de anomalías ante las detecciones.

Clasificador de Objetos - Informe Final de Proyecto | Medina, Fernández, Orrego

## Costos e Insumos

### Materiales y Componentes Adquiridos

En esta sección se detallan los recursos e insumos adquiridos para el ensamblaje y puesta en marcha del prototipo electrónico, basándose en la planilla oficial de costos (con una tasa de cambio de 1 USD = 6,391 PYG).

Tabla 1
Análisis de Costos y Componentes Utilizados (Mouser)
Descripción / Componente | Mfr Part Mouser | Cantida d | Unitario (USD) | Total (USD) | Total (PYG)
Microcontrolador ESP32-S3 | ESP32-S3-WROOM-1-N16R8 | 2.0 | $8.72 | $17.44 | 111,459 Gs.
Regulador LDO (3.3V) | LD1117S33TR | 2.0 | $0.34 | $0.68 | 4,346 Gs.
Driver de Motor H-Bridge | DRV8873SPWPRQ1 | 2.0 | $4.13 | $8.26 | 52,790 Gs.
Conector USB Tipo C Hembra | USB4510-03-1-A | 1.0 | $0.84 | $0.84 | 5,368 Gs.
Módulo de Cámara OV5640 | 5840 (Adafruit) | 1.0 | $9.95 | $9.95 | 63,590 Gs.
Servomotor (DFRobot) | SER0006 | 1.0 | $3.63 | $3.63 | 23,199 Gs.
Diodo Schottky 40V 1A | SS14F-HF | 4.0 | $0.32 | $1.28 | 8,180 Gs.
Capacitor Cerámico 10nF 0805 | CL21B103KBANNNC | 6.0 | $0.10 | $0.60 | 3,835 Gs.
Capacitor Cerámico 47nF 0805 | CL21B473KBCNNNC | 6.0 | $0.10 | $0.60 | 3,835 Gs.
Capacitor Cerámico 100nF 0805 | CL21B104KBCNNNC | 6.0 | $0.10 | $0.60 | 3,835 Gs.
Capacitor Cerámico 220nF 0805 | CL21B224KBFNNNE | 6.0 | $0.10 | $0.60 | 3,835 Gs.
Capacitor Cerámico 470nF 0805 | CL21B474KOFNNNE | 6.0 | $0.10 | $0.60 | 3,835 Gs.
Capacitor Cerámico 1uF 0805 | CL21B105KAFNNNE | 6.0 | $0.10 | $0.60 | 3,835 Gs.
Capacitor Cerámico 2.2uF 0805 | CL21B225KOFNNNE | 6.0 | $0.12 | $0.72 | 4,602 Gs.
Capacitor Cerámico 4.7uF 0805 | CL21B475KOFNNNE | 6.0 | $0.25 | $1.50 | 9,587 Gs.
Capacitor Cerámico 10uF 0805 | CL21B106KOQNNNE | 6.0 | $0.14 | $0.84 | 5,368 Gs.
Capacitor Cerámico 22uF 0805 | CL21A226MQQNNNE | 6.0 | $0.13 | $0.78 | 4,985 Gs.
Capacitor Electrolítico 100uF | EEE-FK1H101P | 6.0 | $0.76 | $4.56 | 29,143 Gs.

Clasificador de Objetos - Informe Final de Proyecto | Medina, Fernández, Orrego
Descripción / Componente | Mfr Part Mouser | Cantida d | Unitario (USD) | Total (USD) | Total (PYG)
Resistencia 0 Ohm 0805 | RC0805JR-070RL | 6.0 | $0.10 | $0.60 | 3,835 Gs.
Resistencia 100 Ohm 0805 | RC0805FR-07100RL | 6.0 | $0.10 | $0.60 | 3,835 Gs.
Resistencia 220 Ohm 0805 | RC0805FR-07220RL | 6.0 | $0.10 | $0.60 | 3,835 Gs.
Resistencia 1k Ohm 0805 | RC0805FR-071KL | 6.0 | $0.10 | $0.60 | 3,835 Gs.
Resistencia 1.5k Ohm 0805 | RC0805FR-071K5L | 6.0 | $0.10 | $0.60 | 3,835 Gs.
Resistencia 2.2k Ohm 0805 | RC0805FR-072K2L | 6.0 | $0.10 | $0.60 | 3,835 Gs.
Resistencia 3.3k Ohm 0805 | RC0805FR-073K3L | 6.0 | $0.10 | $0.60 | 3,835 Gs.
Resistencia 4.7k Ohm 0805 | RC0805FR-074K7L | 6.0 | $0.10 | $0.60 | 3,835 Gs.
Resistencia 5.1k Ohm 0805 | RC0805FR-075K1L | 6.0 | $0.10 | $0.60 | 3,835 Gs.
Resistencia 6.8k Ohm 0805 | RC0805FR-076K8L | 6.0 | $0.10 | $0.60 | 3,835 Gs.
Resistencia 10k Ohm 0805 | RC0805FR-0710KL | 6.0 | $0.11 | $0.66 | 4,218 Gs.
Resistencia 15k Ohm 0805 | RC0805FR-0715KL | 6.0 | $0.13 | $0.78 | 4,985 Gs.
Resistencia 47k Ohm 0805 | RC0805FR-0747KL | 6.0 | $0.10 | $0.60 | 3,835 Gs.
Total Invertido | | 120.0 | | $62.12 | 397,009 Gs.

Nota: El costo por persona (dividido entre los 3 integrantes de trabajo) asciende a 132,336 Gs. (aprox. $20.71 USD).

### Materiales y Herramientas Preexistentes

Tabla 2
Inventario de Componentes Preexistentes y Materiales Disponibles
Descripción | Cantidad
Motor DC NOVAMAX 6V 800 RPM | 2
Sensor Fotoeléctrico Infrarrojo E18-D80NK | 1

Clasificador de Objetos - Informe Final de Proyecto | Medina, Fernández, Orrego

## Metodología y Programación

### Procedimiento de Montaje de la PCB

El ensamblaje de los componentes electrónicos sobre la PCB se ejecutó bajo control visual óptico y térmico, garantizando la correcta integración del microcontrolador ESP32-S3 y sus periféricos.

- Herramientas y Materiales: Placa de calor, microscopio estereofónico, estación de soldadura (cautín y aire caliente), estarcido (stencil), espátula, pinzas de precisión, pasta de soldar, flux, alcohol isopropílico y paños para sala limpia.
- Procedimiento Operatorio:
1. Aplicación de pasta de soldar: Se alineó y fijó el stencil sobre la PCB con cinta de papel. Con la espátula se distribuyó la pasta de forma homogénea. Se retiró el exceso y se verificó la cobertura uniforme de los pads bajo el microscopio.
2. Colocación de componentes (Pick and Place): Tras retirar el stencil, se posicionaron manualmente con pinzas todos los componentes superficiales (SMD), previamente organizados para agilizar el proceso.
3. Refundición y Retoques: La placa se colocó en la placa de calor hasta lograr la fusión de la pasta. Posteriormente, se inspeccionó en el microscopio y se usó la estación de aire caliente con flux para corregir imperfecciones menores.
4. Soldadura de componentes de inserción (THT): El conector USB-C, los botones de control y los conectores de interfaz se soldaron directamente a mano con el cautín para garantizar mayor resistencia mecánica. Finalmente, la PCB se limpió con alcohol isopropílico.

### Avances en la Programación y Flujo del Algoritmo

Librerías Utilizadas

- `"esp_camera.h"` e `"img_converters.h"`: Configuran el sensor de la cámara OV5640 en formato nativo YUV422 (resolución SVGA 800x600), gestionan el búfer de imagen en la PSRAM del ESP32-S3 y realizan la compresión a JPEG mediante software.
- `<WiFi.h>`: Establece la conectividad inalámbrica y la gestión de enlace con el punto de acceso WiFi local.
- `<HTTPClient.h>`: Facilita la estructuración y despacho de las solicitudes HTTP `POST` en formato multipart hacia el webhook del servidor autoalojado.
- `<ESP32Servo.h>`: Controla el servomotor por PWM asignando los timers de hardware LEDC 2 y 3, evitando interferir con el timer 0 (reservado para el reloj maestro de la cámara).

Algoritmos Implementados

- Codificación Base64 (`b64_encode`): Rutina nativa que procesa secuencialmente el archivo JPEG en la PSRAM para convertirlo a texto sin saturar la memoria dinámica.

Clasificador de Objetos - Informe Final de Proyecto | Medina, Fernández, Orrego
- Envío Multipart (`sendToWebhook`): Empaqueta de forma síncrona el string Base64 y el archivo binario JPEG bajo una misma frontera física (`MULTIPART_FORM_DATA`), enviándolo al Webhook del servidor autoalojado.
- Analizador JSON (`parseColor`): Algoritmo simplificado que busca índices de subcadenas para aislar y extraer directamente el valor de la etiqueta `"color"` en la respuesta del servidor.
- Control de Actuadores (`procesarColor`): Evalúa el color retornado por la IA del servidor. Si es `"verde"`, el brazo deflector se mantiene neutro (servo a 0°). Si es `"amarillo"`, gira el servo a 90° por 5 segundos antes de retornar a 0°. Si es `"rojo"`, gira el servo a 180° por 5 segundos antes de retornar a 0°. El motor de la cinta se apaga al detectar el objeto mediante el sensor IR y se vuelve a encender inmediatamente después de actuar el servomotor para reiniciar el ciclo.

### Flujo Conceptual del Algoritmo Final

El objetivo de desarrollo final busca integrar la secuencia de control local de movimiento (Motor DC y Sensor de Proximidad Infrarrojo E18-D80NK) con el bucle supervisor de visión artificial por IoT que se comunica con el servidor autoalojado. El flujo lógico completo se detalla en el siguiente diagrama conceptual:

Figura 3
Diagrama de Flujo Lógico y Secuencia de Control del Sistema Integrado

Clasificador de Objetos - Informe Final de Proyecto | Medina, Fernández, Orrego

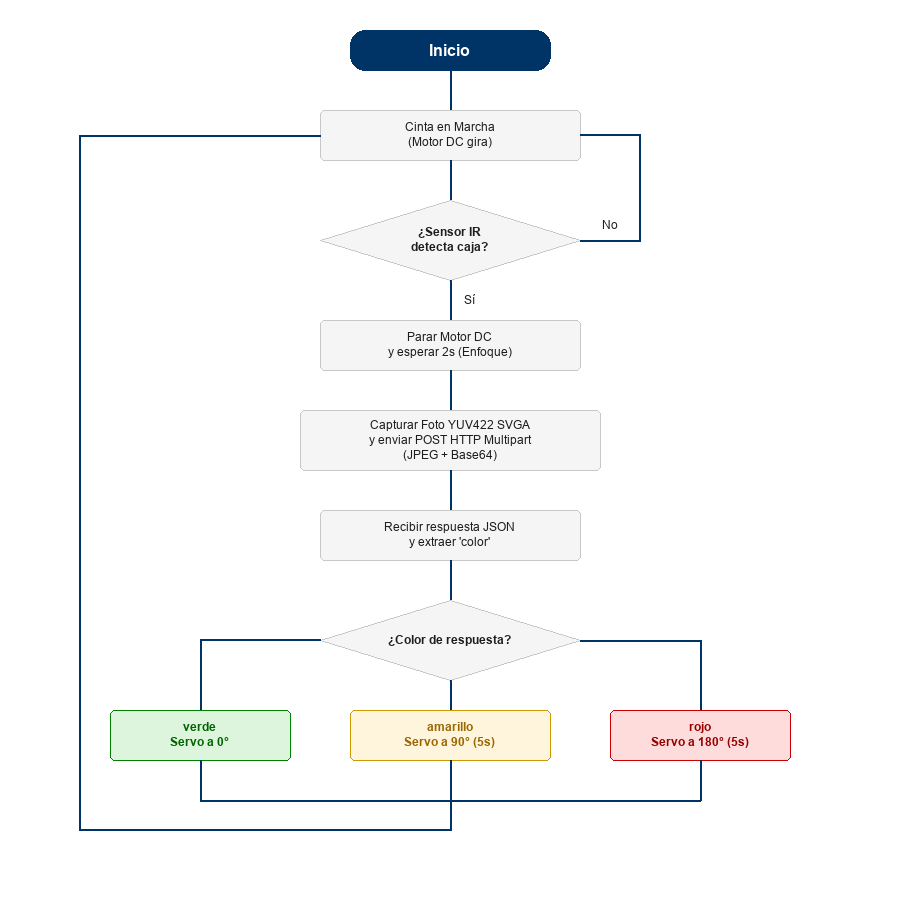
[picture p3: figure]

Diagrama de Flujo Lógico y Secuencia de Control

Clasificador de Objetos - Informe Final de Proyecto | Medina, Fernández, Orrego

## Resultados de Pruebas Aisladas

- Subsistema de Adquisición Óptica: Se validó con éxito la inicialización de la cámara OV5640. El bus de datos opera de manera continua capturando fotogramas SVGA almacenados en la PSRAM.
- Conectividad y Servidor de IA: Se comprobó la estabilidad de la red WiFi del ESP32-S3. Las transmisiones simultáneas del payload en Base64 y binario hacia el servidor autoalojado se ejecutan correctamente, recibiendo de forma síncrona la respuesta del modelo de IA dentro de los márgenes previstos.
- Subsistema de Clasificación Mecánica: El servomotor responde con precisión angular a las instrucciones directas de la IA (giros de 90° o 180° según el color detectado) empleando los canales PWM independientes, cumpliendo rigurosamente el tiempo de retención programado de 5 segundos.
- Ensayos Pendientes: Validada la integración de la cámara, la IA y el servomotor, resta únicamente probar de forma aislada el sensor de proximidad infrarrojo (E18-D80NK) y el motor DC principal con su driver de potencia (DRV8873) para finalizar por completo el proyecto.

Clasificador de Objetos - Informe Final de Proyecto | Medina, Fernández, Orrego

## Resultados Finales

### Resultados Cuantificables

Desempeño Electromecánico
Durante el ciclo continuo de evaluación, el motor de la cinta mantuvo un desplazamiento uniforme operando a una frecuencia PWM de 20 kHz con un ciclo de trabajo del 39.2 %. El servomotor respondió a las instrucciones de desvío con un tiempo medio de retención de 5012 ms frente a los 5000 ms teóricos configurados en el firmware (0.24 % de desviación). En la etapa de potencia, la línea lógica regulada a 3.3 V registró una media estable de 3.27 V, absorbiendo sin reinicios o caídas de tensión los picos de corriente de 2.1 A producidos durante las detenciones y arranques del motor de tracción.

Tiempos de Respuesta y Precisión del Sistema
En el análisis del sistema en funcionamiento continuo, se determinó que el tiempo promedio requerido por cada caja para completar el ciclo de ejecución total (desde la detección inicial por el sensor infrarrojo, la parada de la cinta, la captura y envío de la imagen, la inferencia y retorno del resultado del servidor, y el accionamiento final del servomotor) es de 1 minuto.

Para evaluar la precisión del algoritmo de visión artificial trabajando en conjunto con la temporización de la cinta, se procesó un lote de control integrado por 30 cajas. Los resultados obtenidos se exponen en la Tabla 3\.

Tabla 3
Desempeño del Sistema de Clasificación Visual en Lazo Cerrado
Categoría real | Unidades evaluadas | Clasificación correcta | Errores registrados
Válido (Verde) | 10 | 9 | 1 Falla de identificación por multi-objeto (desviado como "amarillo")
Anómalo (Amarillo) | 10 | 10 | 0
Anómalo (Rojo) | 10 | 9 | 1 Falla de encuadre óptico (clasificado como "verde")
Totales | 30 | 28 | Tasa de efectividad global: 93.33 %

La integración entre el control local y el servidor autoalojado alcanzó una efectividad del 93.33 %, demostrando una sincronización correcta entre el movimiento de la cinta y las respuestas del servidor. Al examinar los dos únicos fallos del lote de control, se determinó que respondieron a factores ópticos y lógicos puntuales, descartando problemas de ruido eléctrico o caídas en la red inalámbrica.

El primer error ocurrió con una caja roja (anómala) que se clasificó como verde (válida). Al revisar la captura, se constató un problema de encuadre en el momento del disparo: el defecto físico de la caja quedó fuera del campo visual (FOV) de la cámara OV5640. Por lo tanto, el modelo evaluó una superficie

Clasificador de Objetos - Informe Final de Proyecto | Medina, Fernández, Orrego

limpia y asignó la categoría normal basándose únicamente en la información visible.

El segundo fallo involucró a una caja conforme que terminó desviada como anomalía (amarillo). Esto se debió a una restricción del propio código del backend; al tomar la fotografía, la siguiente caja de la fila apareció parcialmente en el fondo de la imagen. Como la lógica del programa bloquea la identificación si detecta más de un objeto en el encuadre para evitar falsos positivos, el servidor retornó por defecto el estado amarillo, lo que obligó al ESP32-S3 a mover el servomotor a 90° e interceptar la pieza por seguridad.

Figura 4
Análisis Comparativo de Clasificaciones Correctas y Errores del Modelo

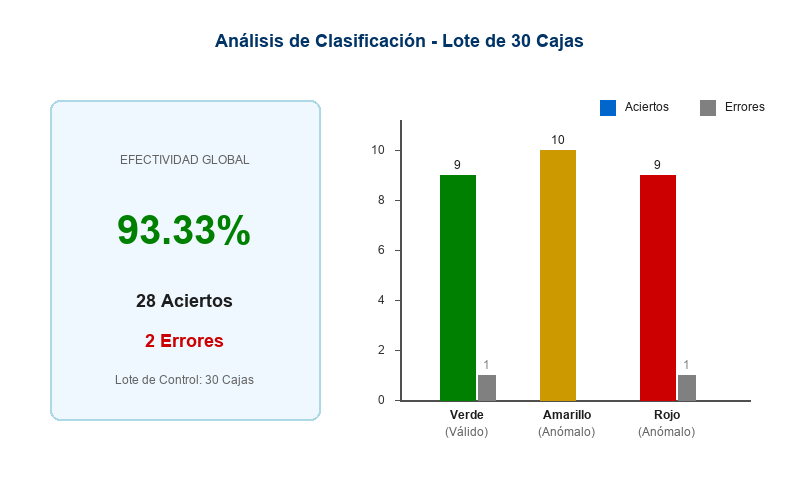
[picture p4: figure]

Análisis Comparativo de Clasificaciones Correctas y Errores del Modelo

Clasificador de Objetos - Informe Final de Proyecto | Medina, Fernández, Orrego

## Conclusiones y Recomendaciones

### Lecciones Aprendidas del Proceso de Integración

Los ensayos demostraron que las decisiones de hardware tomadas en el diseño —como la separación de tierras en la PCB y el uso de memoria RAM externa (ps\_malloc) para los buffers de video— fueron acertadas, ya que mitigaron el ruido electromagnético y evitaron bloqueos por falta de memoria.

Durante la puesta en marcha del sistema óptico, se identificaron y corrigieron dos limitaciones críticas en la configuración de la cámara OV5640:

- Frecuencia del reloj: Inicialmente se configuró por software un reloj por defecto de 8 MHz, lo que provocaba capturas incompletas donde solo se visualizaba la mitad de la imagen. Al revisar las especificaciones técnicas del sensor y el controlador, se determinó configurar una frecuencia de 20 MHz (`cfg.xclk_freq_hz = 20000000`), lo que solucionó por completo el problema de barrido y encuadre óptico.
- Formato de color y nitidez: Al trabajar en formato RGB, la imagen presentaba distorsiones y falta de definición que afectaban el reconocimiento en el backend. La migración al formato nativo YUV422 optimizó la nitidez y el contraste de las capturas, entregando una matriz de datos más limpia para el modelo de clasificación.

### Recomendaciones para Trabajos Futuros

Para optimizar el prototipo actual de forma rápida y viable, se proponen las siguientes mejoras técnicas:

- Aislamiento de la zona de captura: Instalar una pantalla de color uniforme (negro o blanco mate) detrás de la cinta transportadora y colocar dos guías mecánicas simples a los lados. Esto forzará a las cajas a pasar perfectamente centradas frente al lente y evitará que otros objetos en fila aparezcan en el fondo, eliminando los fallos por encuadre o por detección de múltiples objetos.
- Modificar la lógica de error en el servidor autoalojado: Configurar el flujo para que, si el modelo no logra identificar la caja por algún motivo, devuelva un código específico como "desconocido" en lugar del estado operativo "amarillo". De este modo, se podrá programar el ESP32-S3 para que detenga la cinta y encienda un indicador luminoso para una revisión manual.

Clasificador de Objetos - Informe Final de Proyecto | Medina, Fernández, Orrego

## Bibliografía

[1] Y. C. et al., "Design and Implementation of a Low-Cost IoT-Based Robotic Arm for Product Feeding and Sorting in Manufacturing Lines," MDPI, vol. 14, 2024\.
[2] M. S. et al., "Color based product sorting machine using embedded vision and IoT," Int. Journal of Novel Research and Development (IJNRD), 2024\.
[3] L. Osés, B. Pezet, M. Salina, J. Osio, M. Cappelletti, y M. Morales, "Sistema de clasificación de objetos para un recolector de residuos inteligente mediante visión artificial y aprendizaje profundo," en 11° Congreso Nacional de Ingenierías en Informática y Sistemas de Información, 2023\.
[4] A. K. et al., "Development of Real-Time Crop Sorting System Based on Deep Learning and ESP32-CAM Integration," Scientific Research Publishing (SCIRP), 2024\.
[5] Espressif Systems, "ESP32-S3 Series Datasheet v1.8," 2024\. [En línea]. Disponible en: [https://www.espressif.com](https://www.espressif.com)
[6] Texas Instruments, "DRV8873-Q1 Automotive H-Bridge Motor Driver," Texas Instruments, Dallas, TX, USA, Doc. SLVSEB1C, 2021\.
[7] Omnivision Technologies, "OV5640 Color CMOS QSXGA (5 megapixel) Image Sensor with OmniBSI Technology," Datasheet, v2.03.
[8] Texas Instruments, "LM1117 800-mA, Low-Dropout Linear Regulator," Texas Instruments, Dallas, TX, USA, Doc. SNOS412O, 2016\.

Clasificador de Objetos - Informe Final de Proyecto | Medina, Fernández, Orrego

## Anexos

A continuación se presentan las fotografías del proceso de ensamblaje de la PCB, los planos del diseño electrónico y la integración final del sistema sobre la cinta transportadora.

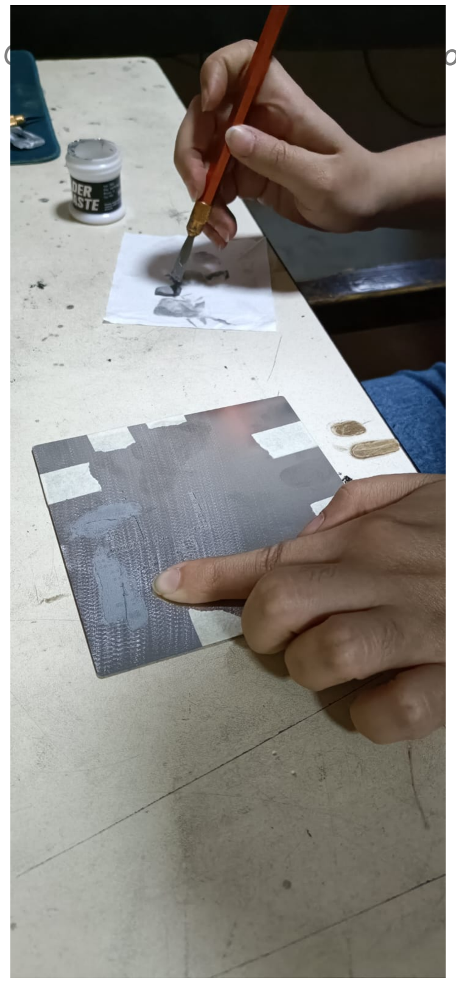
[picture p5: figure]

Clasificador de Objetos - Informe Final de Proyecto | Medina, Fernández, Orrego

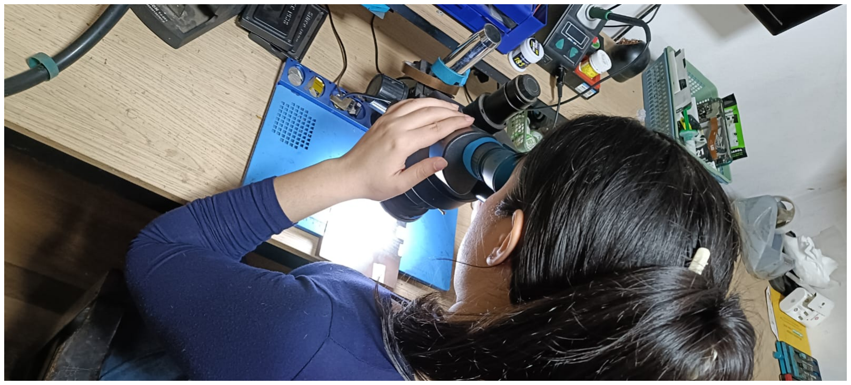
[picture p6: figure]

Aplicación de pasta de soldar con stencil | Inspección con microscopio estereofónico

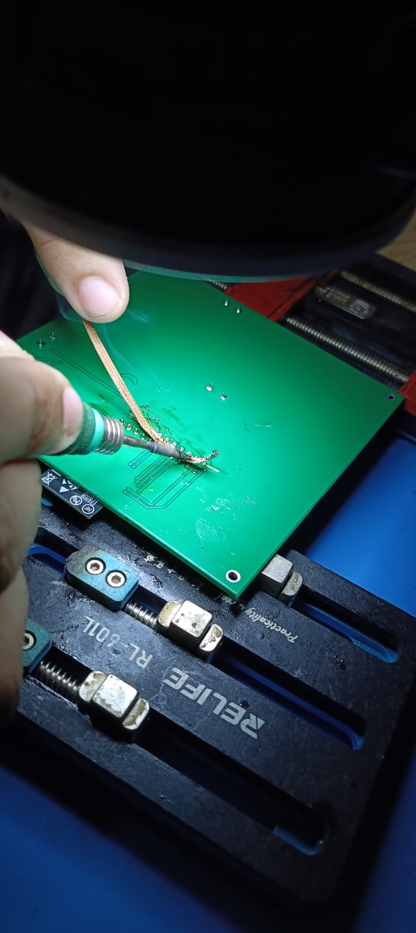
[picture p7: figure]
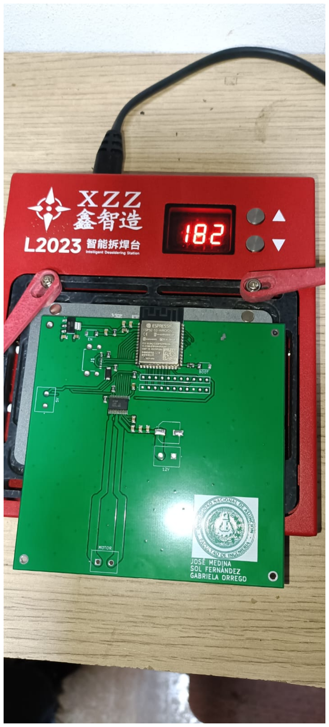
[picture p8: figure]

Soldadura manual con cautín y malla | Refundición de componentes en placa de calor

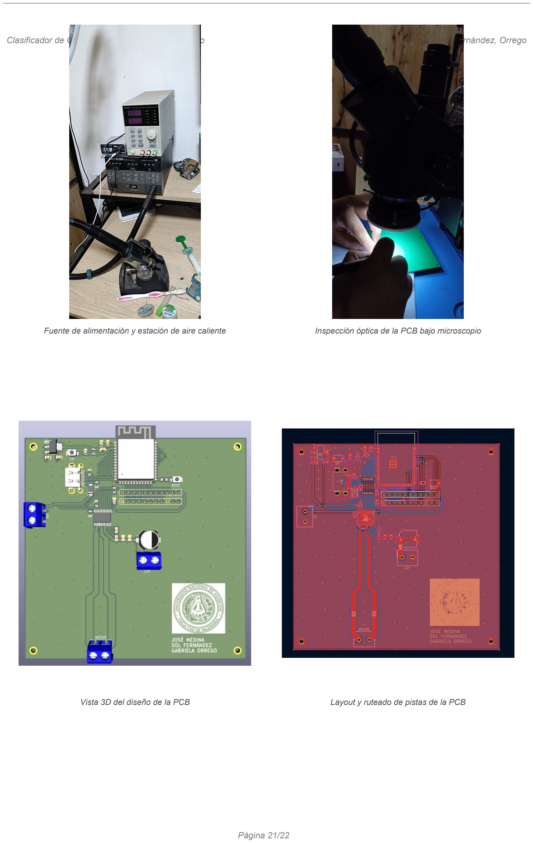
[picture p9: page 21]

Clasificador de Objetos - Informe Final de Proyecto | Medina, Fernández, Orrego
Fuente de alimentación y estación de aire caliente | Inspección óptica de la PCB bajo microscopio
Vista 3D del diseño de la PCB | Layout y ruteado de pistas de la PCB

Clasificador de Objetos - Informe Final de Proyecto | Medina, Fernández, Orrego

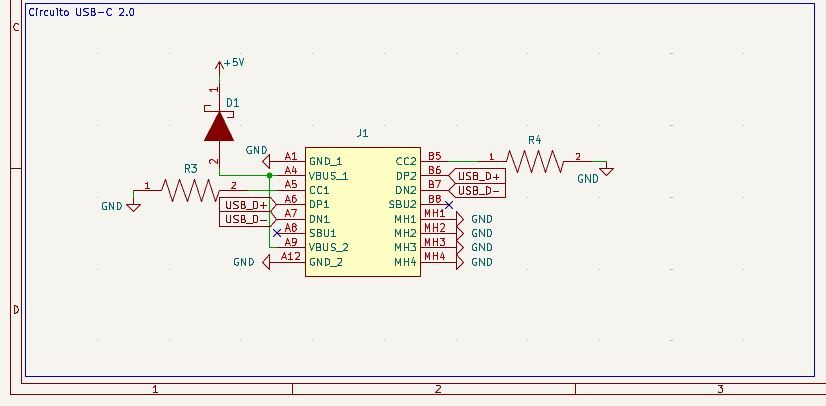
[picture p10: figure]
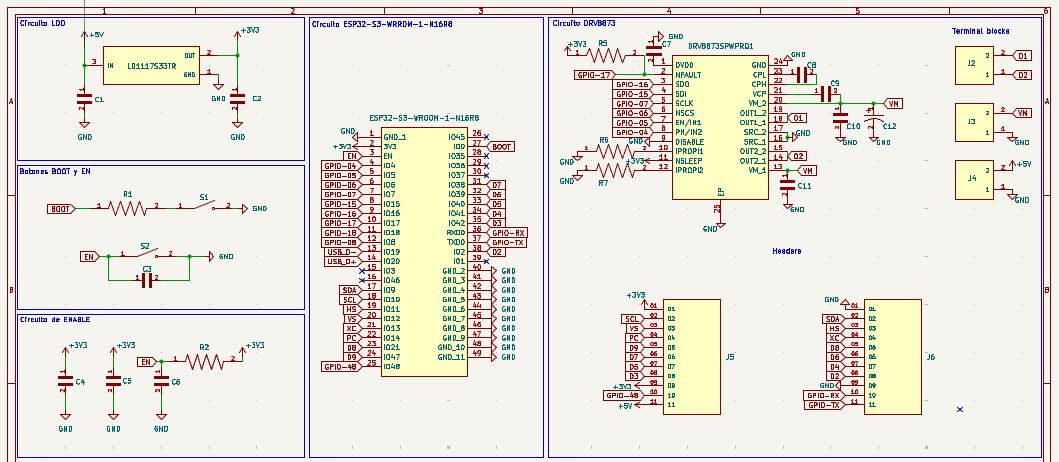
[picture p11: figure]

Esquemático general del circuito | Esquemático del circuito USB-C 2.0

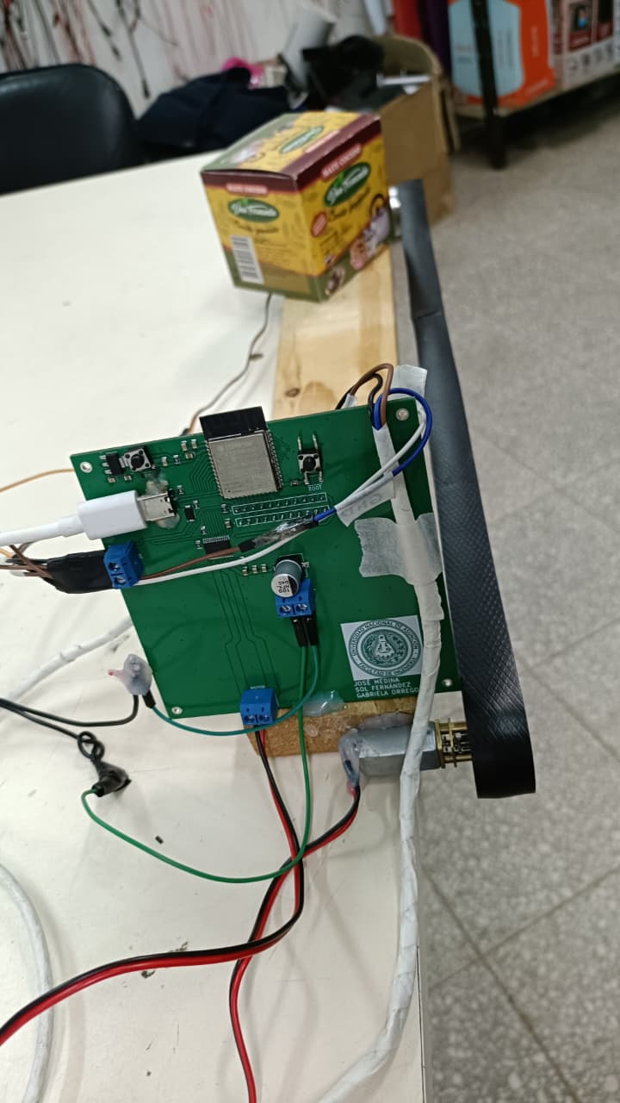
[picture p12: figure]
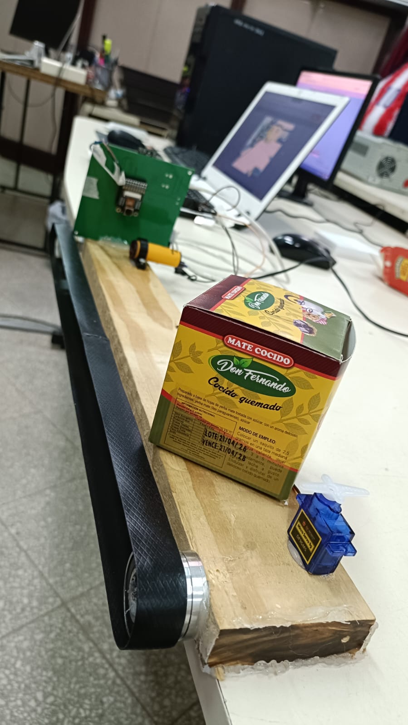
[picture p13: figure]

Integración de la PCB en la cinta transportadora | Sistema completo en funcionamiento

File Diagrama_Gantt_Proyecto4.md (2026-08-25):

# Diagrama de Gantt y Estado de Avances - Proyecto 4: Clasificador de Objetos con IA
**2do Ciclo 2026 | Universidad Nacional de Asunción - Facultad de Ingeniería (FIUNA)**

> **Fecha de corte de avance / Hoy:** 24 de Agosto de 2026

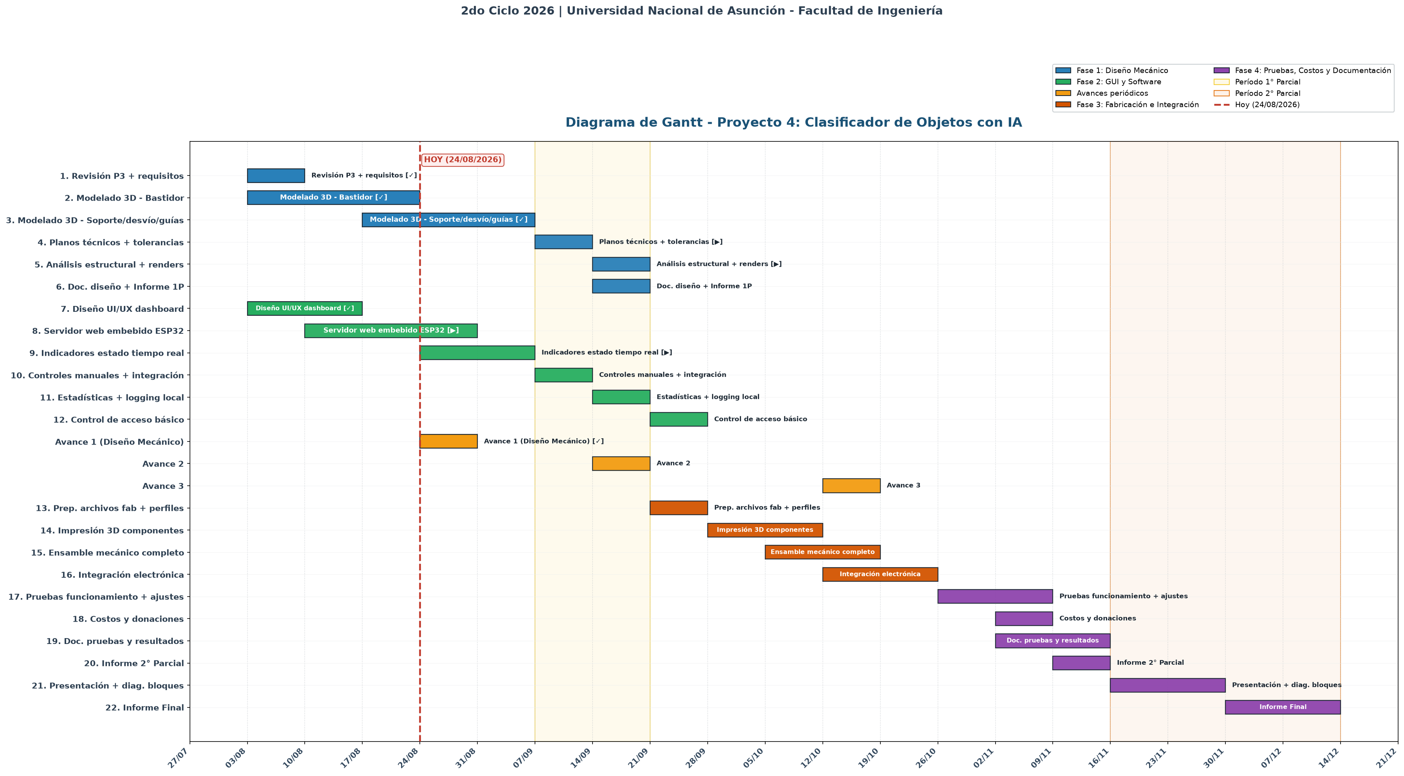
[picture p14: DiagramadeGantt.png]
Diagrama de Gantt del Proyecto 4


---

## 🎨 Leyenda de Fases y Símbolos

| Color / Estilo | Significado | Descripción |
| :--- | :--- | :--- |
| 🔵 **Azul** | **Fase 1: Diseño Mecánico** | CAD, bastidor, sinfín-corona, mecanismo de Ginebra, planos y FEA. |
| 🟢 **Verde** | **Fase 2: GUI y Software** | Dashboard web embebido en ESP32-S3, indicadores RT, controles y accesos. |
| 🟡 **Amarillo / Dorado** | **Avances periódicos** | Hitos de presentación de avances académicos (Avance 1, 2 y 3). |
| 🟠 **Naranja** | **Fase 3: Fabricación e Integración** | Impresión 3D (PLA/PETG), ensamble de Ginebra, perfilería y cableado. |
| 🟣 **Violeta** | **Fase 4: Pruebas, Costos y Doc.** | Pruebas operativas, optimizaciones, informes parciales y presentación final. |
| 🟡 *Fondo Amarillo* | **Período 1° Parcial** | Ventana de evaluaciones parciales (07/09/2026 - 21/09/2026). |
| 🟠 *Fondo Salmón* | **Período 2° Parcial** | Ventana de evaluaciones parciales (16/11/2026 - 14/12/2026). |
| `[✓]` | **Estado: Completado** | Tarea finalizada al 100%. |
| `[▶]` | **Estado: En Progreso** | Tarea en desarrollo activo a la fecha de corte. |

---

## 📊 Tabla de Tareas y Cronograma Detallado

| # | Tarea / Actividad | Fase | Inicio | Fin | Duración | Estado |
|---|---|---|---|-----|---|:---:|
| 1 | Revisión P3 + requisitos | Diseño Mecánico | 03/08/2026 | 10/08/2026 | 1 sem | `[✓] Completado` |
| 2 | Modelado 3D - Bastidor y Transmisión | Diseño Mecánico | 03/08/2026 | 24/08/2026 | 3 sem | `[✓] Completado` |
| 3 | Modelado 3D - Mecanismo Ginebra / Guías | Diseño Mecánico | 17/08/2026 | 07/09/2026 | 3 sem | `[✓] Completado` |
| 4 | Planos técnicos + tolerancias | Diseño Mecánico | 07/09/2026 | 14/09/2026 | 1 sem | `[▶] En Progreso` |
| 5 | Análisis estructural + renders | Diseño Mecánico | 14/09/2026 | 21/09/2026 | 1 sem | `[▶] En Progreso` |
| 6 | Doc. diseño + Informe 1P | Diseño Mecánico | 14/09/2026 | 21/09/2026 | 1 sem | Pendiente |
| 7 | Diseño UI/UX dashboard | GUI y Software | 03/08/2026 | 17/08/2026 | 2 sem | `[✓] Completado` |
| 8 | Servidor web embebido ESP32 | GUI y Software | 10/08/2026 | 31/08/2026 | 3 sem | `[▶] En Progreso` |
| 9 | Indicadores estado tiempo real | GUI y Software | 24/08/2026 | 07/09/2026 | 2 sem | `[▶] En Progreso` |
| 10 | Controles manuales + integración | GUI y Software | 07/09/2026 | 14/09/2026 | 1 sem | Pendiente |
| 11 | Estadísticas + logging local | GUI y Software | 14/09/2026 | 21/09/2026 | 1 sem | Pendiente |
| 12 | Control de acceso básico | GUI y Software | 21/09/2026 | 28/09/2026 | 1 sem | Pendiente |
| - | **Avance 1 (Diseño Mecánico)** | Avances periódicos | 24/08/2026 | 31/08/2026 | 1 sem | `[✓] Completado` |
| - | **Avance 2** | Avances periódicos | 14/09/2026 | 21/09/2026 | 1 sem | Pendiente |
| - | **Avance 3** | Avances periódicos | 12/10/2026 | 19/10/2026 | 1 sem | Pendiente |
| 13 | Prep. archivos fab + perfiles | Fabricación e Integración | 21/09/2026 | 28/09/2026 | 1 sem | Pendiente |
| 14 | Impresión 3D componentes | Fabricación e Integración | 28/09/2026 | 12/10/2026 | 2 sem | Pendiente |
| 15 | Ensamble mecánico completo | Fabricación e Integración | 05/10/2026 | 19/10/2026 | 2 sem | Pendiente |
| 16 | Integración electrónica | Fabricación e Integración | 12/10/2026 | 26/10/2026 | 2 sem | Pendiente |
| 17 | Pruebas funcionamiento + ajustes | Pruebas, Costos y Doc. | 26/10/2026 | 09/11/2026 | 2 sem | Pendiente |
| 18 | Costos y donaciones | Pruebas, Costos y Doc. | 02/11/2026 | 09/11/2026 | 1 sem | Pendiente |
| 19 | Doc. pruebas y resultados | Pruebas, Costos y Doc. | 02/11/2026 | 16/11/2026 | 2 sem | Pendiente |
| 20 | Informe 2° Parcial | Pruebas, Costos y Doc. | 09/11/2026 | 16/11/2026 | 1 sem | Pendiente |
| 21 | Presentación + diag. bloques | Pruebas, Costos y Doc. | 16/11/2026 | 30/11/2026 | 2 sem | Pendiente |
| 22 | Informe Final | Pruebas, Costos y Doc. | 30/11/2026 | 14/12/2026 | 2 sem | Pendiente |

---

## 🛠️ Avances del Proyecto — Diseño Mecánico Formal (`Machine Design LAB`)

En cumplimiento con la entrega del **Avance 1 (24/08/2026)**, se presenta la integración completa del modelo CAD oficial ubicado en la carpeta **`Machine Design LAB`**:

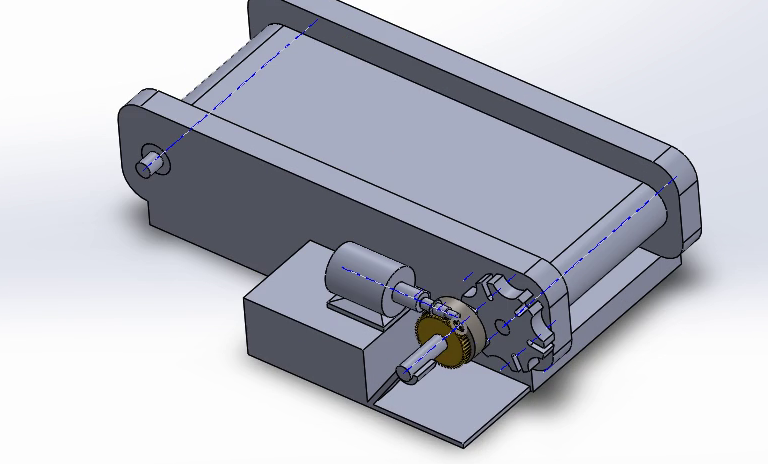
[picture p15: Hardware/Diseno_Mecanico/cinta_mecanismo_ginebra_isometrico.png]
Diseño Mecánico en SolidWorks - Machine Design LAB


### 1. Sistema de Transmisión por Tornillo Sinfín y Corona (100% Completado)
- **Tornillo Sinfín (`worm.SLDPRT`) y Corona (`gear.SLDPRT`):** Reducción de velocidad de rotación del motor eléctrico (`motor.SLDPRT`) acoplada mecánicamente, garantizando auto-frenado e imposibilidad de retroceso por inercia.

### 2. Mecanismo de Ginebra / Cruz de Malta de 6 Posiciones (100% Completado)
- **Rueda de Ginebra (`Geneva_wheel.SLDPRT`):** Mecanismo de 6 ranuras radiales acoplado directamente al eje impulsor (`shaft.SLDPRT`) del rodillo de la cinta transportadora (`conveyor roller.SLDPRT`).
- **Indexación Intermitente Pasos-Pausas:** Convierte el giro continuo del motor en un movimiento de transporte paso a paso con **pausas automáticas de $0.67\text{ s}$**. Durante la pausa, la cámara OV5640 captura la imagen del objeto inmóvil sin desenfoque antes del procesamiento por la IA.

### 3. Informe Técnico de Ingeniería Mecánica
Consulte la documentación y cálculos completos en:
👉 **[Informe_Diseno_Estructural_Mecanico.md](file:///c:/Users/Sol%20Fernandez/.antigravity/Clasificador%20de%20objetos/Hardware/Diseno_Mecanico/Informe_Diseno_Estructural_Mecanico.md)**

---

## 💻 Diagrama de Gantt en Mermaid (Código fuente)

```mermaid
gantt
    title Diagrama de Gantt - Proyecto 4: Clasificador de Objetos con IA (2do Ciclo 2026)
    dateFormat  DD/MM/YYYY
    axisFormat  %d/%m
    section Fase 1: Diseño Mecánico
    1. Revisión P3 + requisitos           :done, a1, 03/08/2026, 7d
    2. Modelado 3D - Bastidor             :done, a2, 03/08/2026, 21d
    3. Modelado 3D - Mecanismo Ginebra    :done, a3, 17/08/2026, 21d
    4. Planos técnicos + tolerancias      :active, a4, 07/09/2026, 7d
    5. Análisis estructural + renders     :active, a5, 14/09/2026, 7d
    6. Doc. diseño + Informe 1P           :a6, 14/09/2026, 7d
    section Fase 2: GUI y Software
    7. Diseño UI/UX dashboard             :done, b1, 03/08/2026, 14d
    8. Servidor web embebido ESP32        :active, b2, 10/08/2026, 21d
    9. Indicadores estado tiempo real     :active, b3, 24/08/2026, 14d
    10. Controles manuales + integración  :b4, 07/09/2026, 7d
    11. Estadísticas + logging local      :b5, 14/09/2026, 7d
    12. Control de acceso básico          :b6, 21/09/2026, 7d
    section Avances periódicos
    Avance 1 (Diseño Mecánico)            :done, c1, 24/08/2026, 7d
    Avance 2                              :crit, c2, 14/09/2026, 7d
    Avance 3                              :crit, c3, 12/10/2026, 7d
    section Fase 3: Fabricación e Integración
    13. Prep. archivos fab + perfiles     :d1, 21/09/2026, 7d
    14. Impresión 3D componentes          :d2, 28/09/2026, 14d
    15. Ensamble mecánico completo        :d3, 05/10/2026, 14d
    16. Integración electrónica           :d4, 12/10/2026, 14d
    section Fase 4: Pruebas, Costos y Doc.
    17. Pruebas funcionamiento + ajustes  :e1, 26/10/2026, 14d
    18. Costos y donaciones               :e2, 02/11/2026, 7d
    19. Doc. pruebas y resultados         :e3, 02/11/2026, 14d
    20. Informe 2° Parcial                :e4, 09/11/2026, 7d
    21. Presentación + diag. bloques      :e5, 16/11/2026, 14d
    22. Informe Final                     :e6, 30/11/2026, 14d
```

---

## 📌 Notas Adicionales
- **Período 1° Parcial**: Aproximadamente del **07/09/2026 al 21/09/2026**.
- **Período 2° Parcial**: Aproximadamente del **16/11/2026 al 14/12/2026**.
- **Visualizador online de Mermaid:** [mermaid.live](https://mermaid.live)

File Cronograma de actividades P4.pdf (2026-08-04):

ID | Fase / Actividad | Responsable | Inicio | Fin | Duración (sem)
1 | 1. Revisión estado P3 + definición requisitos mecánicos | Grupo | 03/08/2026 | 09/08/2026 | 1
2 | 2. Modelado 3D - Bastidor y estructura principal | Sol + José | 03/08/2026 | 23/08/2026 | 3
3 | 3. Modelado 3D - Soporte cámara, desvío y guías contenedores | Gabriela + Sol | 17/08/2026 | 06/09/2026 | 3
4 | 4. Generación de planos técnicos (vistas, cotas, tolerancias) | Grupo | 31/08/2026 | 13/09/2026 | 2
5 | 5. Análisis estructural básico + renderizados fotorealistas | José | 07/09/2026 | 13/09/2026 | 1
6 | 6. Documentación diseño mecánico e Informe 1° Parcial | Grupo | 07/09/2026 | 20/09/2026 | 2
7 | 7. Diseño UI/UX dashboard (wireframes y prototipo) | Sol | 03/08/2026 | 16/08/2026 | 2
8 | 8. Desarrollo servidor web embebido en ESP32-S3 | José | 10/08/2026 | 30/08/2026 | 3
9 | 9. Implementación indicadores de estado en tiempo real | Gabriela | 24/08/2026 | 06/09/2026 | 2
10 | 10. Controles manuales (inicio/parada cinta) + integración | Sol + José | 31/08/2026 | 13/09/2026 | 2
11 | 11. Panel de estadísticas (conteo, tasa aciertos) + logging local | Gabriela | 07/09/2026 | 20/09/2026 | 2
12 | 12. Control de acceso básico a la interfaz web | Sol | 14/09/2026 | 20/09/2026 | 1
13 | Avance 1 (diseño + GUI inicial) | Grupo | 24/08/2026 | 30/08/2026 | 1
14 | Avance 2 (planos + dashboard funcional) | Grupo | 14/09/2026 | 20/09/2026 | 1
15 | Avance 3 (integración y pruebas previas) | Grupo | 12/10/2026 | 18/10/2026 | 1
16 | 13. Preparación archivos impresión 3D + corte perfiles Al | José + Gabriela | 21/09/2026 | 27/09/2026 | 1
17 | 14. Impresión 3D de componentes (PLA/PETG) | Grupo | 28/09/2026 | 11/10/2026 | 2
18 | 15. Ensamble mecánico completo (bastidor + desvío + guías) | Grupo | 05/10/2026 | 18/10/2026 | 2
19 | 16. Integración electrónica (ESP32 + PCB + sensores/actuadores) | Sol + José | 12/10/2026 | 25/10/2026 | 2
20 | 17. Pruebas de funcionamiento y ajustes de IA/cinta | Grupo | 19/10/2026 | 08/11/2026 | 3
21 | 18. Cálculo de costos y registro de donaciones | Gabriela | 26/10/2026 | 01/11/2026 | 1
22 | 19. Documentación de pruebas, resultados parciales y finales | Grupo | 26/10/2026 | 15/11/2026 | 3
23 | 20. Elaboración Informe 2° Parcial | Grupo | 02/11/2026 | 15/11/2026 | 2
24 | 21. Preparación presentación + diagrama de bloques | Grupo | 16/11/2026 | 29/11/2026 | 2
25 | 22. Informe Final + ajustes post-parcial | Grupo | 23/11/2026 | 13/12/2026 | 3

03/08

10/08

17/08

24/08

31/08

07/09

14/09

21/09

28/09

05/10

12/10

19/10

26/10

02/11

09/11

16/11

23/11

30/11

07/12

14/12

# DIAGRAMA DE GANTT - PROYECTO 4 | Clasificador de Objetos con IA | 2do Ciclo 2026

- El diseño mecánico (planos listos para fabricación) y avances de GUI/programación deben estar listos para el 1° Parcial (7-19 Sep 2026).
- Repositorio GitHub debe actualizarse continuamente con commits de cada avance.

## LEYENDA DE COLORES

## NOTAS IMPORTANTES

Fase 3: Fabricación e Integración

Fase 1: Diseño Mecánico

- Considerar asuetos y feriados: 10 Ago, 15 Ago, 12 Sep, 21/24 Sep, 29 Sep. No programar entregas críticas en esas fechas.

Fase 2: GUI y Software

Fase 4: Pruebas, Costos y Documentación

Avances periódicos (entregables)

Periodo 1° Parcial (7-19 Sep)
Periodo 2° Parcial (9-21 Nov)
- Los 3 avances se entregan por WhatsApp o e-mail (aprox. cada 15 días o semanal según docente).

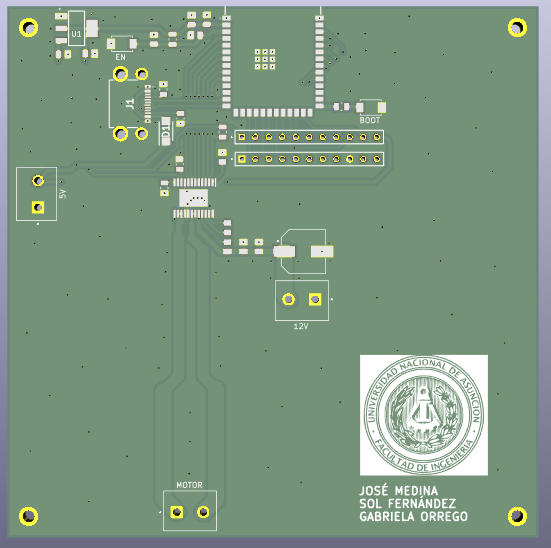
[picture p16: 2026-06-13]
Hardware/pcb_3d.PNG

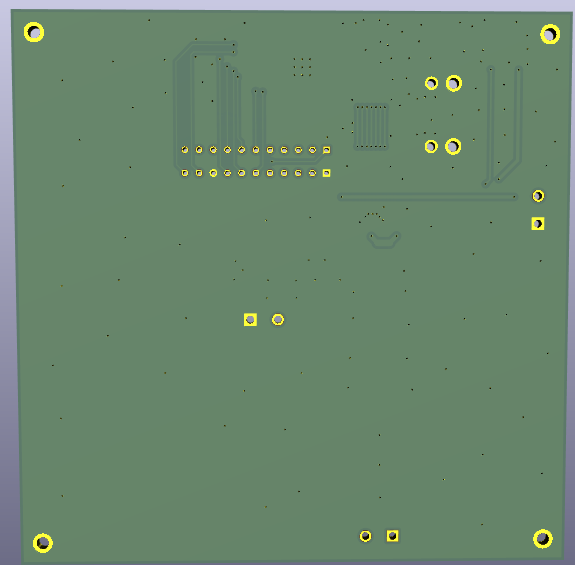
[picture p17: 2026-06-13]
Hardware/pcb_3d_vistinferior.png

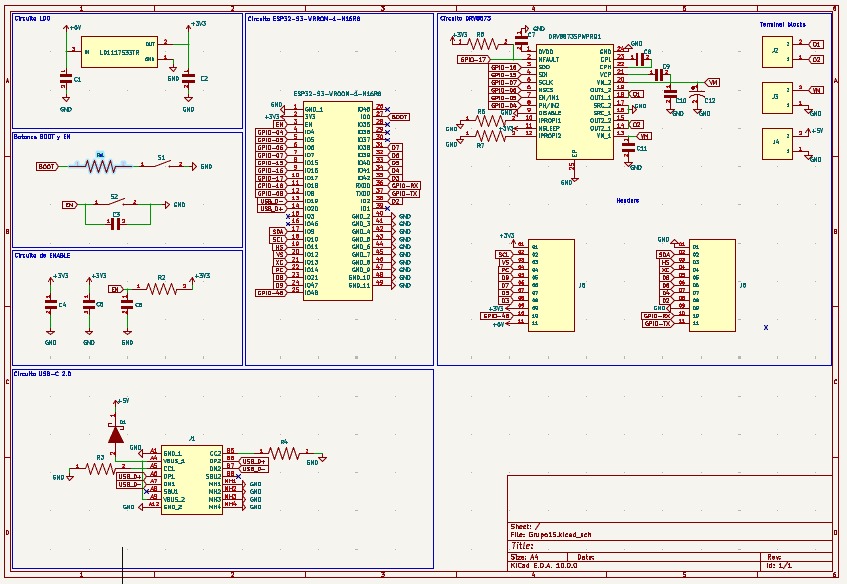
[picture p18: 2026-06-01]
Hardware/Diseño.jpeg

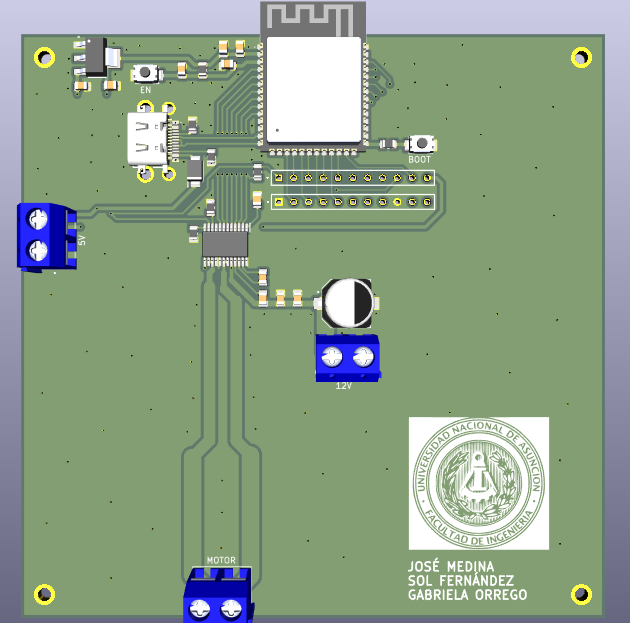
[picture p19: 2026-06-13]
Hardware/pcb_3d_1.png

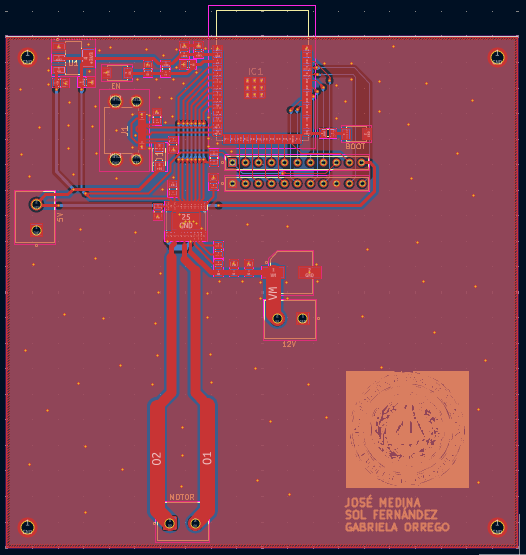
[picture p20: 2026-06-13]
Hardware/pcb_ruteado.PNG

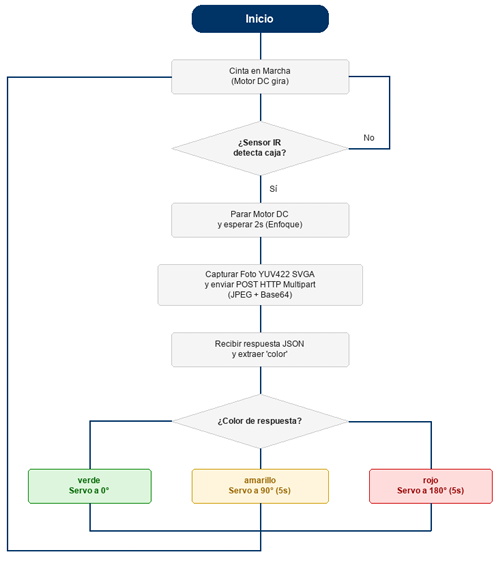
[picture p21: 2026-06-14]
diagrama-flujo.png

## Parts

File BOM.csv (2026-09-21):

Categoría | Componente / Descripción | MPN (Mfr Part Number) | Marca / Fabricante | Cantidad | Unitario (USD) | Total (USD) | Total (PYG) | Proveedor / Link
MCU | Microcontrolador ESP32-S3 | ESP32-S3-WROOM-1-N16R8 | Espressif Systems | 2.0 | 8.72 | 17.44 | 111459 | https://www.mouser.com/ProductDetail/Espressif-Systems/ESP32-S3-WROOM-1-N16R8
LDO | Regulador LDO (3.3V) | LD1117S33TR | STMicroelectronics | 2.0 | 0.34 | 0.68 | 4346 | https://www.mouser.com/ProductDetail/STMicroelectronics/LD1117S33TR
MOTOR | Motor paso a paso NEMA 23 (12.6 kgf-cm) | 23HS5628 | NEMA / Electrónica Paraguay | 1.0 | 46.94 | 46.94 | 300000 | https://electronicaparaguay.com/
USB-C | Conector USB Tipo C Hembra 16 Pines | USB4510-03-1-A | GCT | 1.0 | 0.84 | 0.84 | 5368 | https://www.mouser.com/ProductDetail/GCT/USB4510-03-1-A
CAMERA | Módulo de Cámara OV5640 (5 MP) | 5840 (Adafruit) | Adafruit | 1.0 | 9.95 | 9.95 | 63590 | https://www.adafruit.com/product/5840
SERVO | Servomotor 180 Grados | SER0006 | DFRobot | 1.0 | 3.63 | 3.63 | 23199 | https://www.dfrobot.com/product-2525.html
DIODO | Diodo Schottky 40V 1A | SS14F-HF | Taiwan Semiconductor | 4.0 | 0.32 | 1.28 | 8180 | https://www.mouser.com/ProductDetail/Taiwan-Semiconductor/SS14F-HF
CAPACITOR | Capacitor Cerámico 10nF 0805 | CL21B103KBANNNC | Samsung Electro-Mechanics | 6.0 | 0.10 | 0.60 | 3835 | https://www.mouser.com/ProductDetail/Samsung-Electro-Mechanics/CL21B103KBANNNC
CAPACITOR | Capacitor Cerámico 47nF 0805 | CL21B473KBCNNNC | Samsung Electro-Mechanics | 6.0 | 0.10 | 0.60 | 3835 | https://www.mouser.com/ProductDetail/Samsung-Electro-Mechanics/CL21B473KBCNNNC
CAPACITOR | Capacitor Cerámico 100nF 0805 | CL21B104KBCNNNC | Samsung Electro-Mechanics | 6.0 | 0.10 | 0.60 | 3835 | https://www.mouser.com/ProductDetail/Samsung-Electro-Mechanics/CL21B104KBCNNNC
CAPACITOR | Capacitor Cerámico 220nF 0805 | CL21B224KBFNNNE | Samsung Electro-Mechanics | 6.0 | 0.10 | 0.60 | 3835 | https://www.mouser.com/ProductDetail/Samsung-Electro-Mechanics/CL21B224KBFNNNE
CAPACITOR | Capacitor Cerámico 470nF 0805 | CL21B474KOFNNNE | Samsung Electro-Mechanics | 6.0 | 0.10 | 0.60 | 3835 | https://www.mouser.com/ProductDetail/Samsung-Electro-Mechanics/CL21B474KOFNNNE
CAPACITOR | Capacitor Cerámico 1uF 0805 | CL21B105KAFNNNE | Samsung Electro-Mechanics | 6.0 | 0.10 | 0.60 | 3835 | https://www.mouser.com/ProductDetail/Samsung-Electro-Mechanics/CL21B105KAFNNNE
CAPACITOR | Capacitor Cerámico 2.2uF 0805 | CL21B225KOFNNNE | Samsung Electro-Mechanics | 6.0 | 0.12 | 0.72 | 4602 | https://www.mouser.com/ProductDetail/Samsung-Electro-Mechanics/CL21B225KOFNNNE
CAPACITOR | Capacitor Cerámico 4.7uF 0805 | CL21B475KOFNNNE | Samsung Electro-Mechanics | 6.0 | 0.25 | 1.50 | 9587 | https://www.mouser.com/ProductDetail/Samsung-Electro-Mechanics/CL21B475KOFNNNE
CAPACITOR | Capacitor Cerámico 10uF 0805 | CL21B106KOQNNNE | Samsung Electro-Mechanics | 6.0 | 0.14 | 0.84 | 5368 | https://www.mouser.com/ProductDetail/Samsung-Electro-Mechanics/CL21B106KOQNNNE
CAPACITOR | Capacitor Cerámico 22uF 0805 | CL21A226MQQNNNE | Samsung Electro-Mechanics | 6.0 | 0.13 | 0.78 | 4985 | https://www.mouser.com/ProductDetail/Samsung-Electro-Mechanics/CL21A226MQQNNNE
CAPACITOR | Capacitor Electrolítico 100uF | EEE-FK1H101P | Panasonic | 6.0 | 0.76 | 4.56 | 29143 | https://www.mouser.com/ProductDetail/Panasonic/EEE-FK1H101P
RESISTENCIA | Resistencia 0 Ohm 0805 | RC0805JR-070RL | YAGEO | 6.0 | 0.10 | 0.60 | 3835 | https://www.mouser.com/ProductDetail/YAGEO/RC0805JR-070RL
RESISTENCIA | Resistencia 100 Ohm 0805 | RC0805FR-07100RL | YAGEO | 6.0 | 0.10 | 0.60 | 3835 | https://www.mouser.com/ProductDetail/YAGEO/RC0805FR-07100RL
RESISTENCIA | Resistencia 220 Ohm 0805 | RC0805FR-07220RL | YAGEO | 6.0 | 0.10 | 0.60 | 3835 | https://www.mouser.com/ProductDetail/YAGEO/RC0805FR-07220RL
RESISTENCIA | Resistencia 1k Ohm 0805 | RC0805FR-071KL | YAGEO | 6.0 | 0.10 | 0.60 | 3835 | https://www.mouser.com/ProductDetail/YAGEO/RC0805FR-071KL
RESISTENCIA | Resistencia 1.5k Ohm 0805 | RC0805FR-071K5L | YAGEO | 6.0 | 0.10 | 0.60 | 3835 | https://www.mouser.com/ProductDetail/YAGEO/RC0805FR-071K5L
RESISTENCIA | Resistencia 2.2k Ohm 0805 | RC0805FR-072K2L | YAGEO | 6.0 | 0.10 | 0.60 | 3835 | https://www.mouser.com/ProductDetail/YAGEO/RC0805FR-072K2L
RESISTENCIA | Resistencia 3.3k Ohm 0805 | RC0805FR-073K3L | YAGEO | 6.0 | 0.10 | 0.60 | 3835 | https://www.mouser.com/ProductDetail/YAGEO/RC0805FR-073K3L
RESISTENCIA | Resistencia 4.7k Ohm 0805 | RC0805FR-074K7L | YAGEO | 6.0 | 0.10 | 0.60 | 3835 | https://www.mouser.com/ProductDetail/YAGEO/RC0805FR-074K7L
RESISTENCIA | Resistencia 5.1k Ohm 0805 | RC0805FR-075K1L | YAGEO | 6.0 | 0.10 | 0.60 | 3835 | https://www.mouser.com/ProductDetail/YAGEO/RC0805FR-075K1L
RESISTENCIA | Resistencia 6.8k Ohm 0805 | RC0805FR-076K8L | YAGEO | 6.0 | 0.10 | 0.60 | 3835 | https://www.mouser.com/ProductDetail/YAGEO/RC0805FR-076K8L
RESISTENCIA | Resistencia 10k Ohm 0805 | RC0805FR-0710KL | YAGEO | 6.0 | 0.11 | 0.66 | 4218 | https://www.mouser.com/ProductDetail/YAGEO/RC0805FR-0710KL
RESISTENCIA | Resistencia 15k Ohm 0805 | RC0805FR-0715KL | YAGEO | 6.0 | 0.13 | 0.78 | 4985 | https://www.mouser.com/ProductDetail/YAGEO/RC0805FR-0715KL
RESISTENCIA | Resistencia 47k Ohm 0805 | RC0805FR-0747KL | YAGEO | 6.0 | 0.10 | 0.60 | 3835 | https://www.mouser.com/ProductDetail/YAGEO/RC0805FR-0747KL
SUBTOTAL | Componentes adquiridos e incorporados P4 | - | - | 119.0 | - | 96.06 | 644219 | Tasa oficial de referencia: 1 USD = 6391 PYG. Subtotal componentes comprados Proyecto 4
PREEXISTENTE | Placa propia ESP32-S3 con cámara OV5640 (etapa anterior) | Custom PCB | Proyecto 3 | 1.0 | 0.00 | 0.00 | 0 | Reutilizada de la etapa anterior sin costo adicional
PREEXISTENTE | Servomotor de desvío 180° | SER0006 | DFRobot | 1.0 | 0.00 | 0.00 | 0 | Reutilizado de la etapa anterior
PREEXISTENTE | Controlador L298N para motor paso a paso | L298N Dual H-Bridge | STMicroelectronics | 1.0 | 0.00 | 0.00 | 0 | Etapa de potencia disponible / prestada
PREEXISTENTE | Notebook con servidor n8n autoalojado | Host Local | FIUNA | 1.0 | 0.00 | 0.00 | 0 | Infraestructura de cómputo para flujo de visión IA
PREEXISTENTE | Licencia / Estación SolidWorks CAD | SolidWorks 2024 | FIUNA | 1.0 | 0.00 | 0.00 | 0 | Estación de diseño mecánico y planos técnicos
PREEXISTENTE | Multímetro y herramientas de taller/banco | - | FIUNA / Taller | 1.0 | 0.00 | 0.00 | 0 | Instrumentación y banco de pruebas
TOTAL GENERAL | Costo Total Incremental P4 | - | - | - | - | 96.06 | 644219 | Costo por integrante (3 personas): $32.02 USD (214740 PYG)

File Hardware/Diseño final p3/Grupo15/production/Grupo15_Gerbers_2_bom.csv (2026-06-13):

Designator | Footprint | Quantity | Value | LCSC Part #
12V, 5V, MOTOR | HANDSON_KF301-2P | 3 | KF301-2P
BOOT, EN | SW_TS-1088-AR02016 | 2 | TS-1088-AR02016
C1, C10, C11, C3, C4 | CAPC2012X95N | 5 | CL21B104KBCNNNC
C12 | CAP_EEEFK1H101P | 1 | EEEFK1H101P
C2 | CAPC2012X140N | 1 | CL21B106KOQNNNE
C5 | CAPC2012X140N | 1 | CL21A226MQQNNNE
C6, C7, C9 | CAPC2012X135N | 3 | CL21B105KAFNNNE
C8 | CAPC2012X95N | 1 | CL21B473KBCNNNC
D1 | SODFL4626X120N | 1 | SS14F-HF
H1_2 | SOP65P640X120-25N | 1 | DRV8873SPWPRQ1
IC1 | ESP32S3WROOM1N16R8 | 1 | ESP32-S3-WROOM-1-N16R8
J1 | USB4510031A | 1 | USB4510-03-1-A
J5, J6 | SAMTEC_TS-111-T-A-1 | 2 | TS-111-T-A-1
R1 | RESC2012X60N | 1 | RC0805FR-07100RL
R2, R5 | RESC2012X60N | 2 | RC0805FR-0710KL
R3, R4 | RESC2012X60N | 2 | RC0805FR-075K1L
R6, R7 | RESC2012X60N | 2 | RC0805FR-071K5L
U1 | SOT230P700X180-4N | 1 | LD1117S33TR

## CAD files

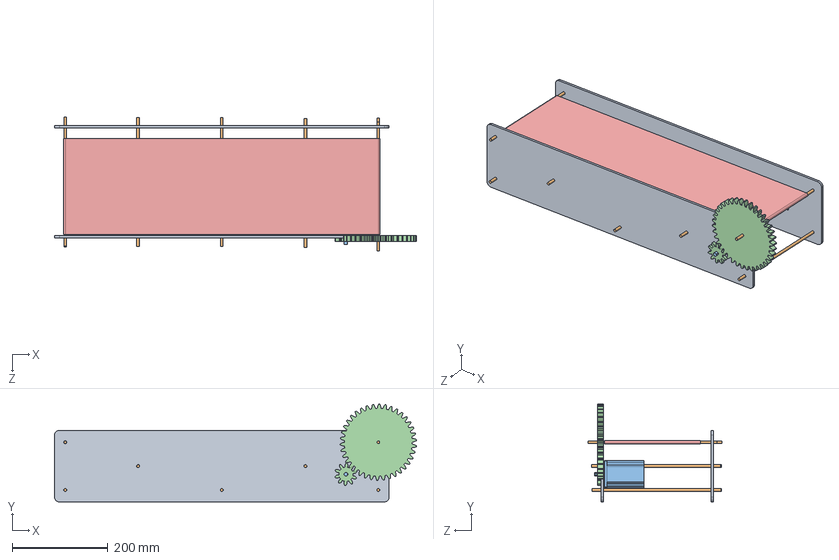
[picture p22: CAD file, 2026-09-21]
Hardware/Diseno_Mecanico/Ensamble.SLDASM
757.4 x 205.0 x 280.5 mm
Tabla x 2
Varilla x 7
nema23
spur gear_am x 2
Cinta

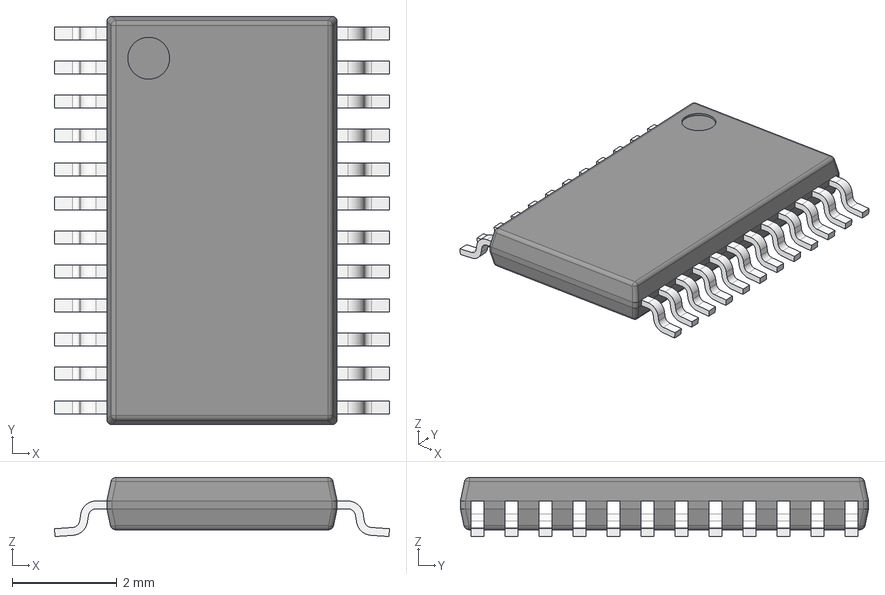
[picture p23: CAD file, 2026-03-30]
Hardware/Componentes/Activos/DRIVER 8873/8873_step/DRV8873SPWPRQ1.stp
6.40 x 7.80 x 1.13 mm
BODY-TSSOP
LEAD-TSSOP x 24
PIN1
DAP

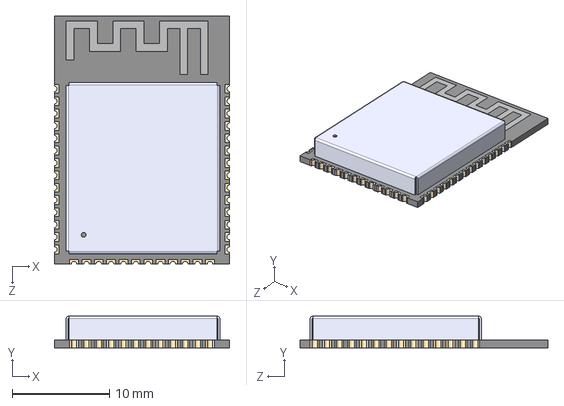
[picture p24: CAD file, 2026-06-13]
Hardware/Componentes/Activos/ESP32 S3 WROOM1 N16R8/espS3_step/ESP32-S3-WROOM-1-N16R8.stp
18.0 x 3.25 x 25.5 mm

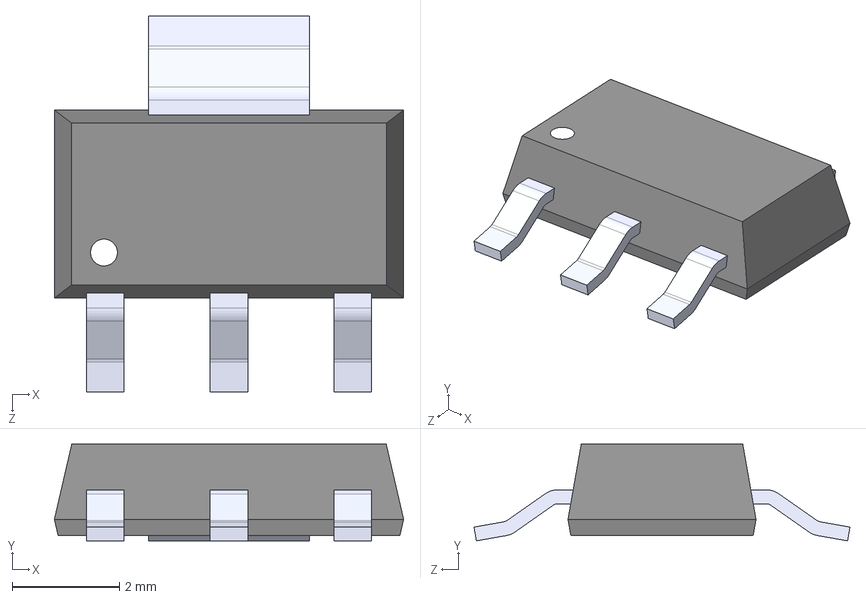
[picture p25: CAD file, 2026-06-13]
Hardware/Componentes/Activos/LDO LD1117S33TR/ldo1117_step/LD1117S33TR.step
6.50 x 1.80 x 7.00 mm

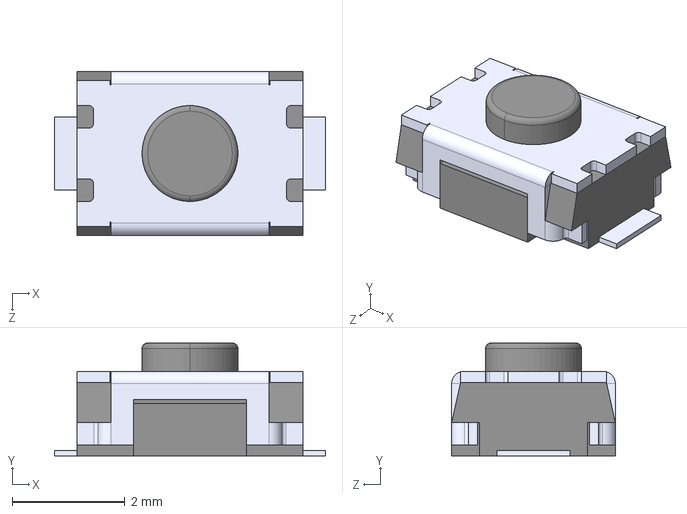
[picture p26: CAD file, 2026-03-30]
Hardware/Componentes/Pasivos/boton/boton_step/TS-1088-AR02016.step
4.80 x 2.00 x 2.90 mm

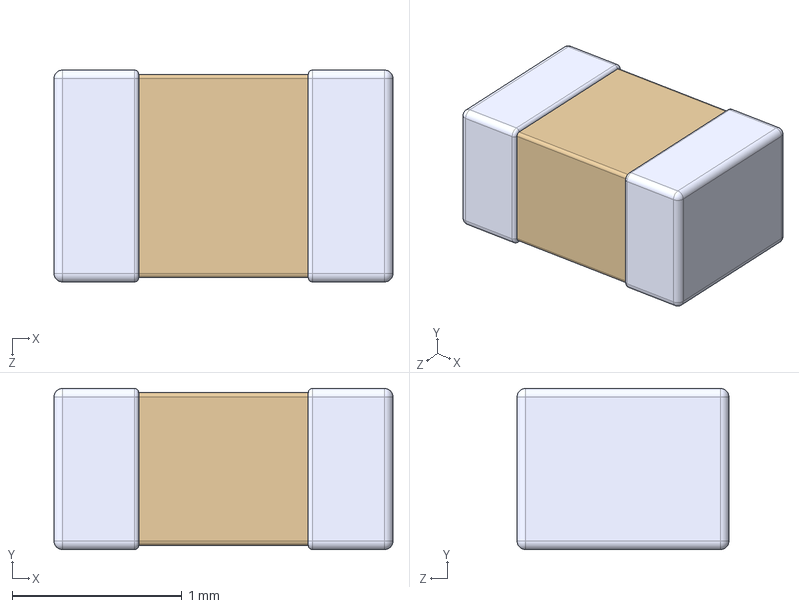
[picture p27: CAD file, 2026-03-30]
Hardware/Componentes/Pasivos/Capacitores/100nF/100nF_step/CL21B104KBCNNNC.step
2.00 x 0.95 x 1.25 mm

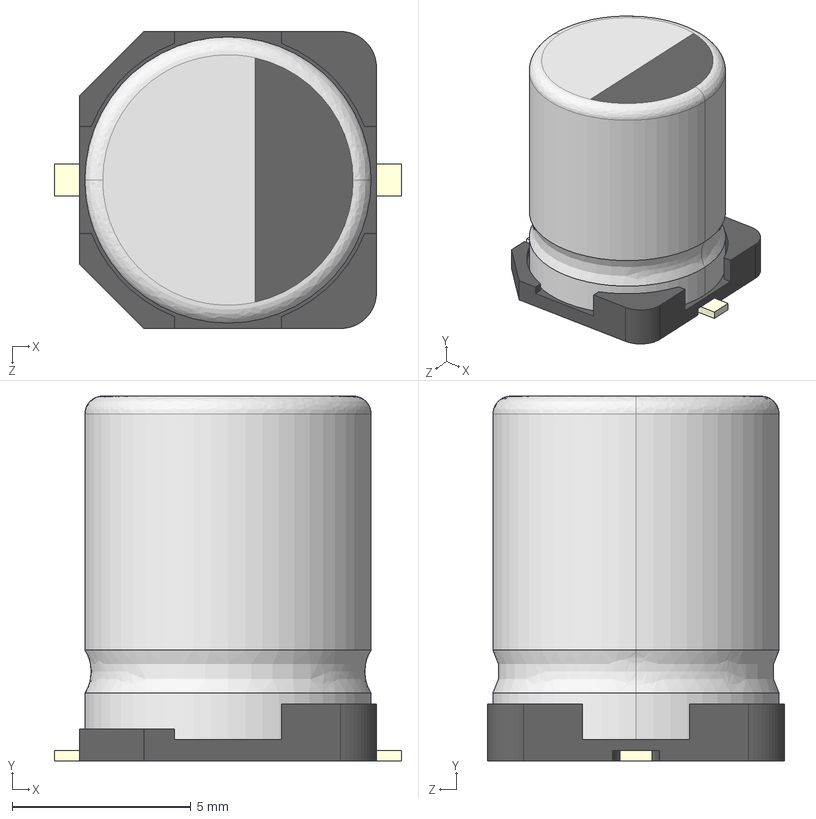
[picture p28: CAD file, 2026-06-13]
Hardware/Componentes/Pasivos/Capacitores/100uF/100uF_step/EEEFK1H101P.step
9.70 x 10.2 x 8.30 mm

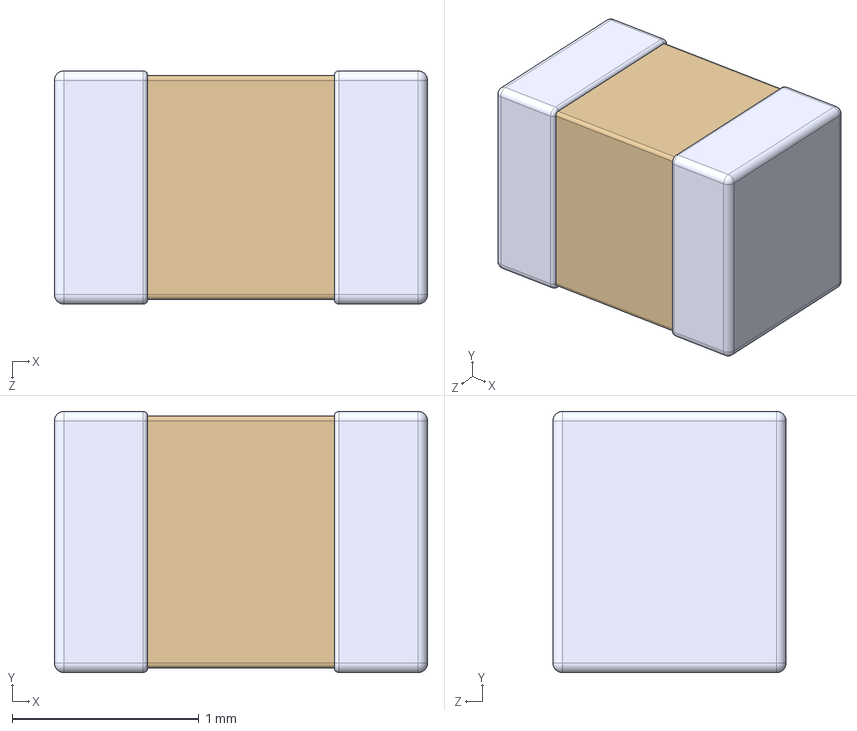
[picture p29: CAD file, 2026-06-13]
Hardware/Componentes/Pasivos/Capacitores/10uF/10uF_step/CL21B106KOQNNNE.step
2.00 x 1.40 x 1.25 mm

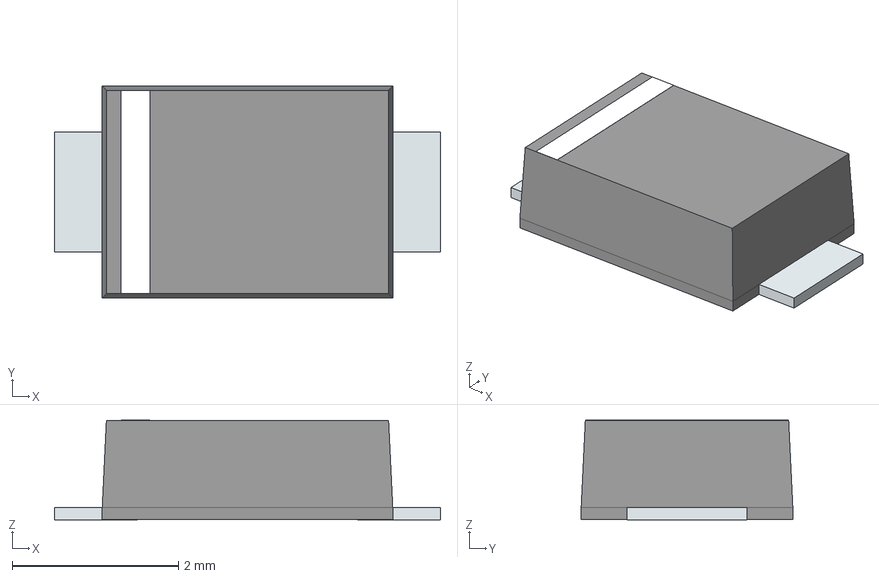
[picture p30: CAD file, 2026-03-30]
Hardware/Componentes/Pasivos/Diodo Schottky/diodo_step/SS14F-HF.stp
4.65 x 2.55 x 1.20 mm
PinKIdent
PinK
PinA

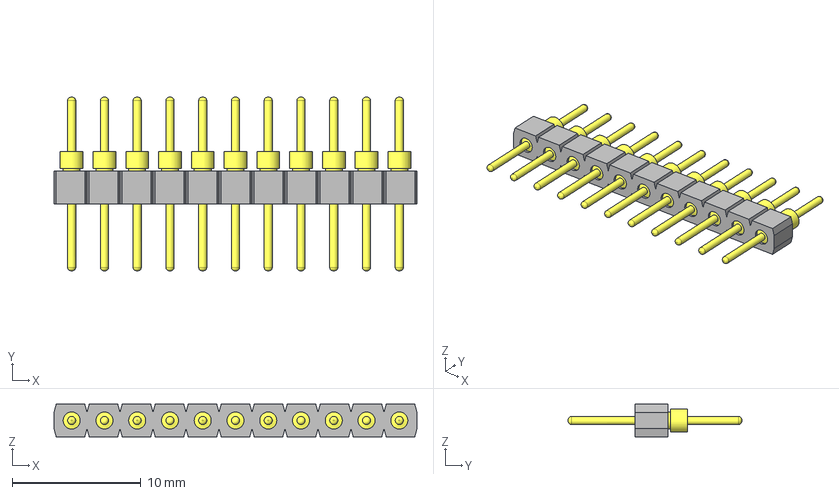
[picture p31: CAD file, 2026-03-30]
Hardware/Componentes/Pasivos/Headers/header_step/TS-111-T-A-1.stp
28.1 x 13.5 x 2.54 mm
TS-111-G-A-1_socket
-101-G-A-1_pins x 11

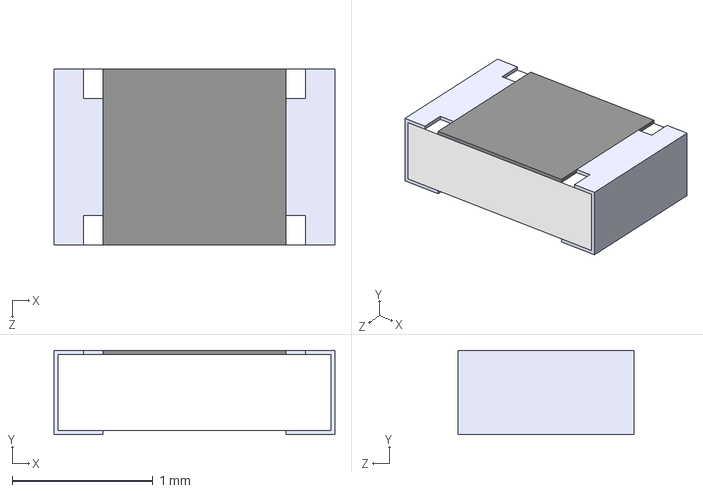
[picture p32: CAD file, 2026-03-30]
Hardware/Componentes/Pasivos/Resistores/1.5k/1.5k_step/RC0805FR-071K5L.step
2.00 x 0.6 x 1.25 mm

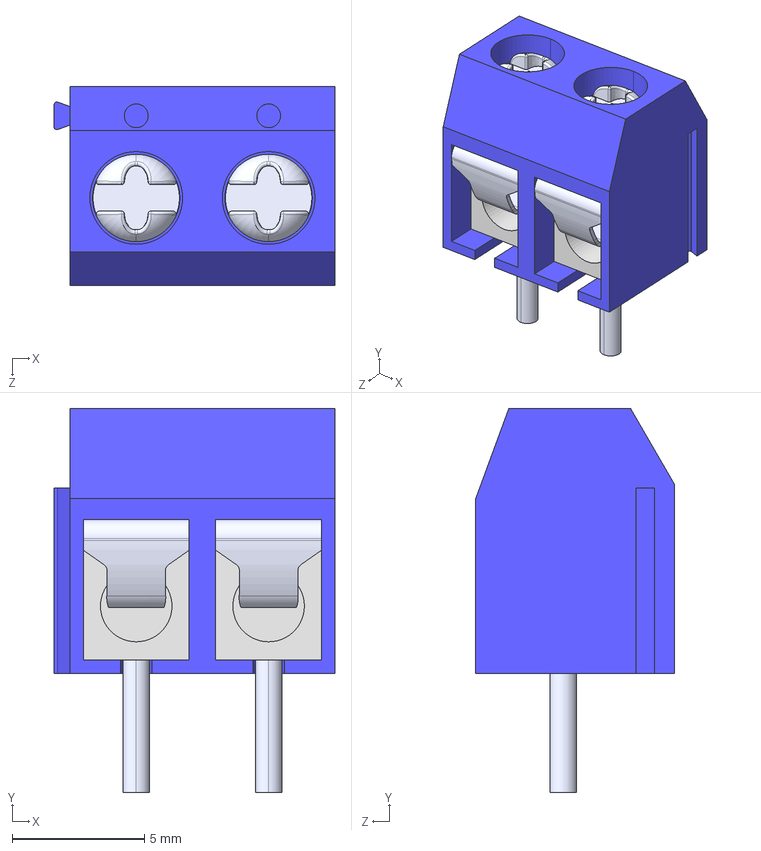
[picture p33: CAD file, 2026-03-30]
Hardware/Componentes/Pasivos/terminal block 2Pin/terminal_step/KF301-2P.step
10.6 x 14.5 x 7.50 mm

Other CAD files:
Hardware/Componentes/Pasivos/Capacitores/1uF/1uF_step/CL21B105KAFNNNE.step
Hardware/Componentes/Pasivos/USB-C 2.0/usb_step/USB4510-03-1-A.stp
Hardware/Diseno_Mecanico/Cinta.SLDPRT
Hardware/Diseno_Mecanico/Engranaje_C.SLDPRT
Hardware/Diseno_Mecanico/Tabla.SLDPRT
Hardware/Diseno_Mecanico/Varilla.SLDPRT
Hardware/Diseno_Mecanico/engranaje_G.SLDPRT
Hardware/Diseno_Mecanico/nema23.SLDPRT

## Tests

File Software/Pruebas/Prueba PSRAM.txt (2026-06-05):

void setup() {
  Serial.begin(115200);
  delay(2000);
  Serial.println("\n=======================================");
  Serial.println("    DIAGNÓSTICO DE PSRAM ESP32-S3      ");
  Serial.println("=======================================");

  // 1. Verificar si el compilador y el hardware detectan la PSRAM
  if (!psramFound()) {
    Serial.println("❌ ERROR CRÍTICO: El hardware NO detecta la PSRAM.");
    Serial.println("👉 Causas posibles:");
    Serial.println("   1. La placa no tiene chip de PSRAM físico.");
    Serial.println("   2. En 'Tools', la placa requiere 'Quad PSRAM' en vez de 'OPI PSRAM'. ");
    return;
  }

  Serial.println("✅ PSRAM dectectada por el sistema.");

  // 2. Mostrar capacidades de memoria
  uint32_t total_psram = (uint32_t)ESP.getPsramSize();
  uint32_t free_psram  = (uint32_t)ESP.getFreePsram();
  
  Serial.printf("💾 Tamaño Total de PSRAM: %u bytes (%.2f MB)\n", total_psram, (float)total_psram / (1024.0 * 1024.0));
  Serial.printf("💾 PSRAM Libre actual:    %u bytes\n", free_psram);

  if (total_psram == 0) {
    Serial.println("❌ ERROR: El tamaño reportado es 0 bytes. La configuración en el IDE es errónea.");
    return;
  }

  // 3. Test de estrés: Intentar reservar, escribir y leer 1 MB de memoria exacta
  uint32_t tamano_test = 1024 * 1024; // 1 Megabyte
  Serial.printf("\n🧠 Solicitando bloque de %u bytes en la PSRAM...\n", tamano_test);

  // Forzamos la asignación específicamente en la PSRAM externa
  char* buffer = (char*)ps_malloc(tamano_test);

  if (buffer == NULL) {
    Serial.println("❌ ERROR: No hay suficiente espacio continuo o la PSRAM falló al asignar memoria.");
    return;
  }
  Serial.println("✅ Bloque asignado con éxito.");

  // Escritura de patrones de prueba
  Serial.println("✍️  Escribiendo datos de prueba en la PSRAM...");
  for (uint32_t i = 0; i < tamano_test; i++) {
    buffer[i] = (i % 26) + 'A'; // Llena el buffer con letras A-Z cíclicamente
  }

  // Lectura y verificación de integridad
  Serial.println("🔍 Verificando integridad de los datos almacenados...");
  bool PSRAM_ok = true;
  for (uint32_t i = 0; i < tamano_test; i++) {
    char esperado = (i % 26) + 'A';
    if (buffer[i] != esperado) {
      Serial.printf("❌ CORRUPCIÓN DE DATOS! En byte %u se esperaba '%c' pero se leyó '%c'\n", i, esperado, buffer[i]);
      PSRAM_ok = false;
      break;
    }
  }

  // Liberar la memoria de prueba inmediatamente
  free(buffer);

  // 4. Veredicto Final
  Serial.println("=======================================");
  if (PSRAM_ok) {
    Serial.println("RESULTADO: PSRAM PERFECTA Y OPERATIVAA! 🎉");
    Serial.println("");
  } else {
    Serial.println("❌ RESULTADO: PSRAM DEFECTUOSA O INESTABLE ❌");
    Serial.println("Pruebemos bajando la velocidad de la CPU a 160MHz o cambiando a 'Quad PSRAM'.");
  }
  Serial.println("=======================================");
}

void loop() {
  // Nada por aquí
}

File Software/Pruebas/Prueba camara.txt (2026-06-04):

#include "esp_camera.h"
#include <WiFi.h>
#include "esp_http_server.h"

// ====== CONFIGURAR WIFI ======
const char* WIFI_SSID = "Bit";
const char* WIFI_PASS = "230899160604";

// ====== Pines OV5640 ======
#define PWDN_GPIO_NUM     -1
#define RESET_GPIO_NUM    -1
#define XCLK_GPIO_NUM     13
#define SIOD_GPIO_NUM      9
#define SIOC_GPIO_NUM     10
#define Y9_GPIO_NUM       47
#define Y8_GPIO_NUM       21
#define Y7_GPIO_NUM       38
#define Y6_GPIO_NUM       39
#define Y5_GPIO_NUM       40
#define Y4_GPIO_NUM       41
#define Y3_GPIO_NUM       42
#define Y2_GPIO_NUM        1
#define VSYNC_GPIO_NUM    12
#define HREF_GPIO_NUM     11
#define PCLK_GPIO_NUM     14

httpd_handle_t server_httpd = NULL;

#define PART_BOUNDARY "123456789000000000000987654321"
static const char* STREAM_CONTENT_TYPE = "multipart/x-mixed-replace;boundary=" PART_BOUNDARY;
static const char* STREAM_BOUNDARY     = "\r\n--" PART_BOUNDARY "\r\n";
static const char* STREAM_PART         = "Content-Type: image/jpeg\r\nContent-Length: %u\r\n\r\n";

// ---------- Capturar UNA foto ----------
static esp_err_t capture_handler(httpd_req_t *req) {
  Serial.println("[capture] cliente conectado");
  camera_fb_t *fb = esp_camera_fb_get();
  if (!fb) {
    Serial.println("[capture] fb_get devolvio NULL");
    httpd_resp_send_500(req);
    return ESP_FAIL;
  }
  Serial.printf("[capture] frame %u bytes\n", (unsigned)fb->len);
  httpd_resp_set_type(req, "image/jpeg");
  httpd_resp_set_hdr(req, "Content-Disposition", "inline; filename=capture.jpg");
  httpd_resp_set_hdr(req, "Access-Control-Allow-Origin", "*");
  httpd_resp_set_hdr(req, "Cache-Control", "no-cache, no-store, must-revalidate");
  esp_err_t res = httpd_resp_send(req, (const char*)fb->buf, fb->len);
  esp_camera_fb_return(fb);
  return res;
}

// ---------- Stream MJPEG ----------
static esp_err_t stream_handler(httpd_req_t *req) {
  Serial.println("[stream] cliente conectado");
  camera_fb_t *fb = NULL;
  esp_err_t res = ESP_OK;
  char hdr[64];

  res = httpd_resp_set_type(req, STREAM_CONTENT_TYPE);
  if (res != ESP_OK) return res;
  httpd_resp_set_hdr(req, "Access-Control-Allow-Origin", "*");
  httpd_resp_set_hdr(req, "Cache-Control", "no-cache, no-store, must-revalidate");
  httpd_resp_set_hdr(req, "Pragma", "no-cache");

  int frames = 0;
  int nulls  = 0;

  while (true) {
    fb = esp_camera_fb_get();
    if (!fb) {
      nulls++;
      if (nulls > 10) { Serial.println("[stream] demasiados null, salgo"); break; }
      vTaskDelay(pdMS_TO_TICKS(100));
      continue;
    }
    nulls = 0;

    if (fb->format != PIXFORMAT_JPEG) {
      esp_camera_fb_return(fb);
      vTaskDelay(pdMS_TO_TICKS(50));
      continue;
    }

    size_t hlen = snprintf(hdr, 64, STREAM_PART, fb->len);
    res = httpd_resp_send_chunk(req, STREAM_BOUNDARY, strlen(STREAM_BOUNDARY));
    if (res == ESP_OK) res = httpd_resp_send_chunk(req, hdr, hlen);
    if (res == ESP_OK) res = httpd_resp_send_chunk(req, (const char*)fb->buf, fb->len);
    esp_camera_fb_return(fb);

    if (res != ESP_OK) { Serial.printf("[stream] cliente cerro tras %d frames\n", frames); break; }
    frames++;
    if (frames % 10 == 0) Serial.printf("[stream] %d frames\n", frames);
    vTaskDelay(pdMS_TO_TICKS(100));
  }
  return res;
}

// ---------- Pagina principal ----------
static esp_err_t index_handler(httpd_req_t *req) {
  const char *html =
    "<!DOCTYPE html><html><head><meta charset='utf-8'>"
    "<meta name='viewport' content='width=device-width,initial-scale=1'>"
    "<title>ESP32-S3 OV5640</title>"
    "<style>"
    "  *{box-sizing:border-box;margin:0;padding:0}"
    "  body{background:#0d0d0d;color:#e0e0e0;font-family:'Courier New',monospace;"
    "       display:flex;flex-direction:column;align-items:center;min-height:100vh;padding:20px}"
    "  h1{font-size:1.2rem;letter-spacing:4px;text-transform:uppercase;color:#00ff99;margin-bottom:6px}"
    "  #status{font-size:0.75rem;color:#888;margin-bottom:16px;height:18px}"
    "  #view{position:relative;width:100%;max-width:640px}"
    "  #cam{width:100%;border:1px solid #333;display:block;background:#111;min-height:200px}"
    "  #overlay{position:absolute;top:50%;left:50%;transform:translate(-50%,-50%);"
    "            color:#00ff99;font-size:0.85rem;pointer-events:none}"
    "  .btn{margin-top:14px;padding:8px 22px;background:transparent;border:1px solid #00ff99;"
    "       color:#00ff99;font-family:inherit;font-size:0.8rem;letter-spacing:2px;"
    "       cursor:pointer;text-transform:uppercase}"
    "  .btn:hover{background:#00ff9922}"
    "  #fps{font-size:0.7rem;color:#555;margin-top:6px}"
    "</style></head>"
    "<body>"
    "<h1>ESP32-S3 &bull; OV5640</h1>"
    "<div id='status'>Iniciando...</div>"
    "<div id='view'>"
    "  "
    "  <div id='overlay'>Conectando...</div>"
    "</div>"
    ""
    "<button class='btn' onclick='toggleStream()' id='btn'>Detener</button>"
    "<script>"
    "var running=true,reader=null,frameCount=0,lastTime=Date.now();"
    "var img=document.getElementById('cam');"
    "var overlay=document.getElementById('overlay');"
    "var status=document.getElementById('status');"
    "var fpsEl=document.getElementById('fps');"
    "setInterval(function(){"
    "  var now=Date.now(),fps=(frameCount*1000/(now-lastTime)).toFixed(1);"
    "  fpsEl.textContent=running?fps+' fps':'';"
    "  frameCount=0;lastTime=now;"
    "},1000);"
    "async function startStream(){"
    "  status.textContent='Conectando...';"
    "  overlay.textContent='Conectando...';"
    "  try{"
    "    var resp=await fetch('/stream');"
    "    if(!resp.ok){throw new Error('HTTP '+resp.status);}"
    "    status.textContent='Stream activo';"
    "    overlay.textContent='';"
    "    reader=resp.body.getReader();"
    "    var buf=new Uint8Array(0);"
    "    function concat(a,b){var c=new Uint8Array(a.length+b.length);c.set(a);c.set(b,a.length);return c;}"
    "    function findSeq(hay,needle,start){"
    "      outer:for(var i=start;i<=hay.length-needle.length;i++){"
    "        for(var j=0;j<needle.length;j++)if(hay[i+j]!==needle[j])continue outer;"
    "        return i;} return -1;}"
    "    var SOI=new Uint8Array([0xFF,0xD8]);"
    "    var EOI=new Uint8Array([0xFF,0xD9]);"
    "    while(running){"
    "      var r=await reader.read();"
    "      if(r.done){console.log('stream done');break;}"
    "      buf=concat(buf,r.value);"
    "      var s=findSeq(buf,SOI,0);"
    "      if(s<0){buf=new Uint8Array(0);continue;}"
    "      var e=findSeq(buf,EOI,s+2);"
    "      if(e<0)continue;"
    "      var jpeg=buf.slice(s,e+2);"
    "      buf=buf.slice(e+2);"
    "      var old=img.src;"
    "      img.src=URL.createObjectURL(new Blob([jpeg],{type:'image/jpeg'}));"
    "      if(old.startsWith('blob:'))URL.revokeObjectURL(old);"
    "      frameCount++;"
    "    }"
    "  }catch(err){"
    "    status.textContent='Error: '+err.message;"
    "    overlay.textContent='Sin senal';"
    "    console.error('stream error:',err);"
    "    if(running)setTimeout(startStream,3000);"
    "  }"
    "}"
    "function toggleStream(){"
    "  var btn=document.getElementById('btn');"
    "  if(running){"
    "    running=false;btn.textContent='Iniciar';"
    "    status.textContent='Detenido';"
    "    if(reader)reader.cancel();"
    "  }else{"
    "    running=true;btn.textContent='Detener';"
    "    startStream();"
    "  }"
    "}"
    "startStream();"
    "</script>"
    "</body></html>";

  httpd_resp_set_type(req, "text/html");
  httpd_resp_set_hdr(req, "Cache-Control", "no-cache");
  return httpd_resp_send(req, html, strlen(html));
}

void startCameraServer() {
  httpd_config_t config = HTTPD_DEFAULT_CONFIG();
  config.server_port      = 80;
  config.stack_size       = 16384;
  config.max_uri_handlers = 8;

  httpd_uri_t u_index   = { .uri = "/",        .method = HTTP_GET, .handler = index_handler,   .user_ctx = NULL };
  httpd_uri_t u_capture = { .uri = "/capture", .method = HTTP_GET, .handler = capture_handler, .user_ctx = NULL };
  httpd_uri_t u_stream  = { .uri = "/stream",  .method = HTTP_GET, .handler = stream_handler,  .user_ctx = NULL };

  if (httpd_start(&server_httpd, &config) == ESP_OK) {
    httpd_register_uri_handler(server_httpd, &u_index);
    httpd_register_uri_handler(server_httpd, &u_capture);
    httpd_register_uri_handler(server_httpd, &u_stream);
    Serial.println("Servidor HTTP arrancado.");
  } else {
    Serial.println("Fallo httpd_start");
  }
}

bool initCamera() {
  esp_camera_deinit();
  delay(300);

  camera_config_t config = {};
  config.ledc_channel = LEDC_CHANNEL_0;
  config.ledc_timer   = LEDC_TIMER_0;
  config.pin_d0 = Y2_GPIO_NUM; config.pin_d1 = Y3_GPIO_NUM;
  config.pin_d2 = Y4_GPIO_NUM; config.pin_d3 = Y5_GPIO_NUM;
  config.pin_d4 = Y6_GPIO_NUM; config.pin_d5 = Y7_GPIO_NUM;
  config.pin_d6 = Y8_GPIO_NUM; config.pin_d7 = Y9_GPIO_NUM;
  config.pin_xclk     = XCLK_GPIO_NUM;    config.pin_pclk     = PCLK_GPIO_NUM;
  config.pin_vsync    = VSYNC_GPIO_NUM;   config.pin_href     = HREF_GPIO_NUM;
  config.pin_sccb_sda = SIOD_GPIO_NUM;    config.pin_sccb_scl = SIOC_GPIO_NUM;
  config.pin_pwdn     = PWDN_GPIO_NUM;    config.pin_reset    = RESET_GPIO_NUM;

  // Paso 1: init en RGB565 — fuerza reset completo del sensor
  // El OV5640 a veces arranca mal en JPEG directo
  config.xclk_freq_hz = 20000000;
  config.pixel_format = PIXFORMAT_RGB565;
  config.frame_size   = FRAMESIZE_QVGA;
  config.jpeg_quality = 12;
  config.fb_count     = 1;
  config.grab_mode    = CAMERA_GRAB_WHEN_EMPTY;
  config.fb_location  = CAMERA_FB_IN_PSRAM;

  esp_err_t err = esp_camera_init(&config);
  if (err != ESP_OK) {
    Serial.printf("ERROR init RGB565 (0x%x)\n", err);
    return false;
  }
  Serial.println("Init RGB565 OK — reseteando sensor...");

  // Captura algunos frames en RGB para despertar el sensor
  for (int i = 0; i < 5; i++) {
    camera_fb_t *fb = esp_camera_fb_get();
    if (fb) {
      Serial.printf("  RGB frame %d: %u bytes\n", i, (unsigned)fb->len);
      esp_camera_fb_return(fb);
    } else {
      Serial.printf("  RGB frame %d: NULL\n", i);
    }
    delay(150);
  }

  // Paso 2: switch a JPEG via sensor register
  sensor_t *s = esp_camera_sensor_get();
  if (s) {
    s->set_pixformat(s, PIXFORMAT_JPEG);
    s->set_framesize(s, FRAMESIZE_QVGA);
    s->set_quality(s, 12);
    s->set_brightness(s, 0);
    s->set_contrast(s, 0);
    s->set_saturation(s, 0);
    s->set_whitebal(s, 1);
    s->set_awb_gain(s, 1);
    s->set_wb_mode(s, 0);
    s->set_exposure_ctrl(s, 1);
    s->set_aec2(s, 0);
    s->set_gain_ctrl(s, 1);
    s->set_agc_gain(s, 0);
    s->set_gainceiling(s, (gainceiling_t)0);
    s->set_bpc(s, 0);
    s->set_wpc(s, 1);
    s->set_raw_gma(s, 1);
    s->set_lenc(s, 1);
    s->set_hmirror(s, 0);
    s->set_vflip(s, 0);
    Serial.println("Sensor configurado en JPEG.");
  }

  delay(500); // espera a que el sensor aplique el cambio de formato

  // Paso 3: reinit con JPEG y fb_count=2
  esp_camera_deinit();
  delay(200);

  config.pixel_format = PIXFORMAT_JPEG;
  config.fb_count     = 2;

  err = esp_camera_init(&config);
  if (err != ESP_OK) {
    Serial.printf("ERROR init JPEG (0x%x)\n", err);
    return false;
  }
  Serial.println("Camara OK en JPEG.");

  // Configura sensor de nuevo tras reinit
  s = esp_camera_sensor_get();
  if (s) {
    s->set_framesize(s, FRAMESIZE_QVGA);
    s->set_quality(s, 12);
    s->set_whitebal(s, 1);
    s->set_awb_gain(s, 1);
    s->set_exposure_ctrl(s, 1);
    s->set_gain_ctrl(s, 1);
    s->set_raw_gma(s, 1);
    s->set_lenc(s, 1);
  }

  // Warm-up final
  Serial.println("Warm-up JPEG...");
  int ok = 0;
  for (int i = 0; i < 10; i++) {
    camera_fb_t *fb = esp_camera_fb_get();
    if (fb) {
      Serial.printf("  jpeg frame %d: %u bytes\n", i, (unsigned)fb->len);
      esp_camera_fb_return(fb);
      ok++;
    } else {
      Serial.printf("  jpeg frame %d: NULL\n", i);
    }
    delay(150);
  }

  if (ok == 0) {
    Serial.println("ERROR: ningun frame JPEG valido en warm-up");
    return false;
  }

  Serial.printf("Warm-up OK (%d/%d frames validos)\n", ok, 10);
  return true;
}

void setup() {
  Serial.begin(115200);
  Serial.setDebugOutput(true);
  delay(2000);
  Serial.println("\n=== OV5640 streaming ===");

  if (!initCamera()) {
    Serial.println("Reintentando en 3s...");
    delay(3000);
    if (!initCamera()) {
      Serial.println("FATAL: camara no disponible");
      return;
    }
  }

  WiFi.mode(WIFI_STA);
  WiFi.begin(WIFI_SSID, WIFI_PASS);
  Serial.print("Conectando WiFi");
  int intentos = 0;
  while (WiFi.status() != WL_CONNECTED) {
    delay(300);
    Serial.print(".");
    if (++intentos > 40) {
      Serial.println("\nERROR: WiFi timeout");
      return;
    }
  }
  Serial.println();
  Serial.print(">>> http://");
  Serial.print(WiFi.localIP());
  Serial.println("/");

  startCameraServer();
}

void loop() {
  delay(10000);
}

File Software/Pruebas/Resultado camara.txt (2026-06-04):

== OV5640 streaming ===
Camara OK.
Sensor configurado.
Warm-up OK.
Conectando WiFi...........
>>> http://192.168.100.197/        (pagina con video)
>>> http://192.168.100.197/capture (una foto JPEG)
>>> http://192.168.100.197/stream  (raw MJPEG)
Servidor HTTP arrancado.
[stream] cliente conectado

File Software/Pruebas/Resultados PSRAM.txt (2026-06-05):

=======================================

    DIAGNÓSTICO DE PSRAM ESP32-S3      

=======================================

✅ PSRAM dectectada por el sistema.

💾 Tamaño Total de PSRAM: 8388608 bytes (8.00 MB)

💾 PSRAM Libre actual:    8386096 bytes

🧠 Solicitando bloque de 1048576 bytes en la PSRAM...

✅ Bloque asignado con éxito.

✍️  Escribiendo datos de prueba en la PSRAM...

🔍 Verificando integridad de los datos almacenados...

=======================================

RESULTADO: PSRAM PERFECTA Y OPERATIVAA! 🎉

=======================================

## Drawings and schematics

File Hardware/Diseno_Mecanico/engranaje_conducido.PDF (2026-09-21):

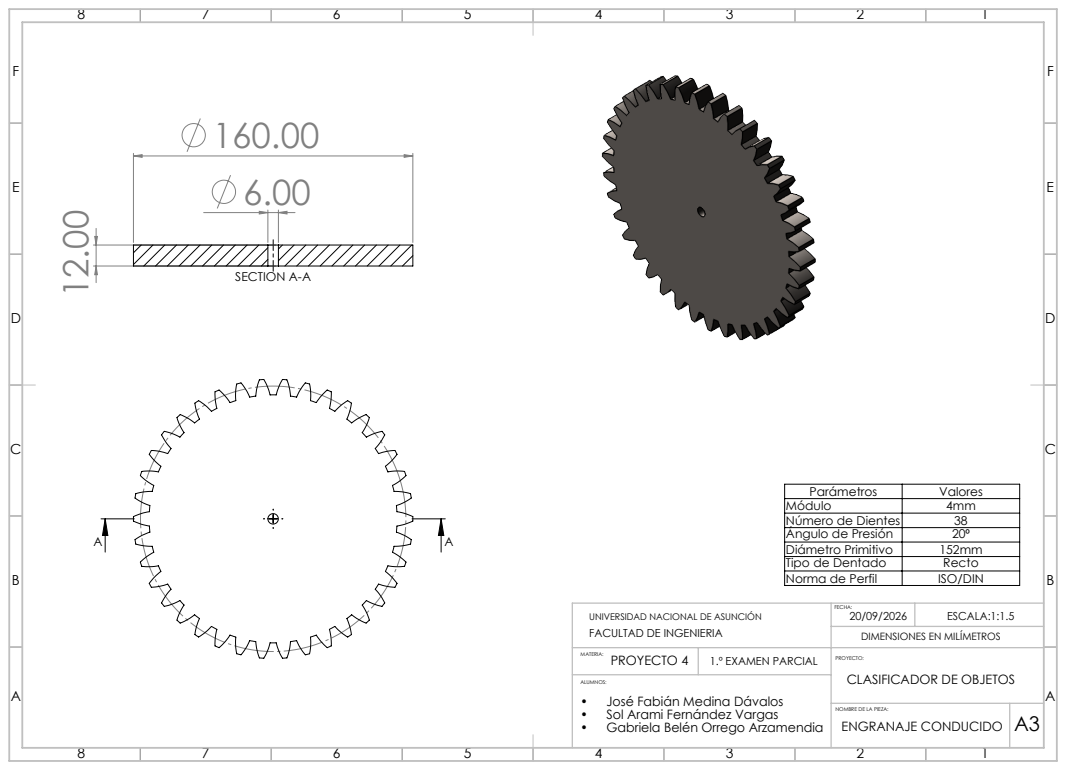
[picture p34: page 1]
SECTION A-A; 1.º EXAMEN PARCIAL; DIMENSIONES EN MILÍMETROS

Parámetros | Valores
Módulo | 4mm
Número de Dientes | 38
Ángulo de Presión | 20º
Diámetro Primitivo | 152mm
Tipo de Dentado | Recto
Norma de Perfil | ISO/DIN

UNIVERSIDAD NACIONAL DE ASUNCIÓN
FACULTAD DE INGENIERIA
PROYECTO 4

PROYECTO:
CLASIFICADOR DE OBJETOS

ALUMNOS:
• José Fabián Medina Dávalos
• Sol Arami Fernández Vargas • Gabriela Belén Orrego Arzamendia

NOMBRE DE LA PIEZA:
ENGRANAJE CONDUCIDO

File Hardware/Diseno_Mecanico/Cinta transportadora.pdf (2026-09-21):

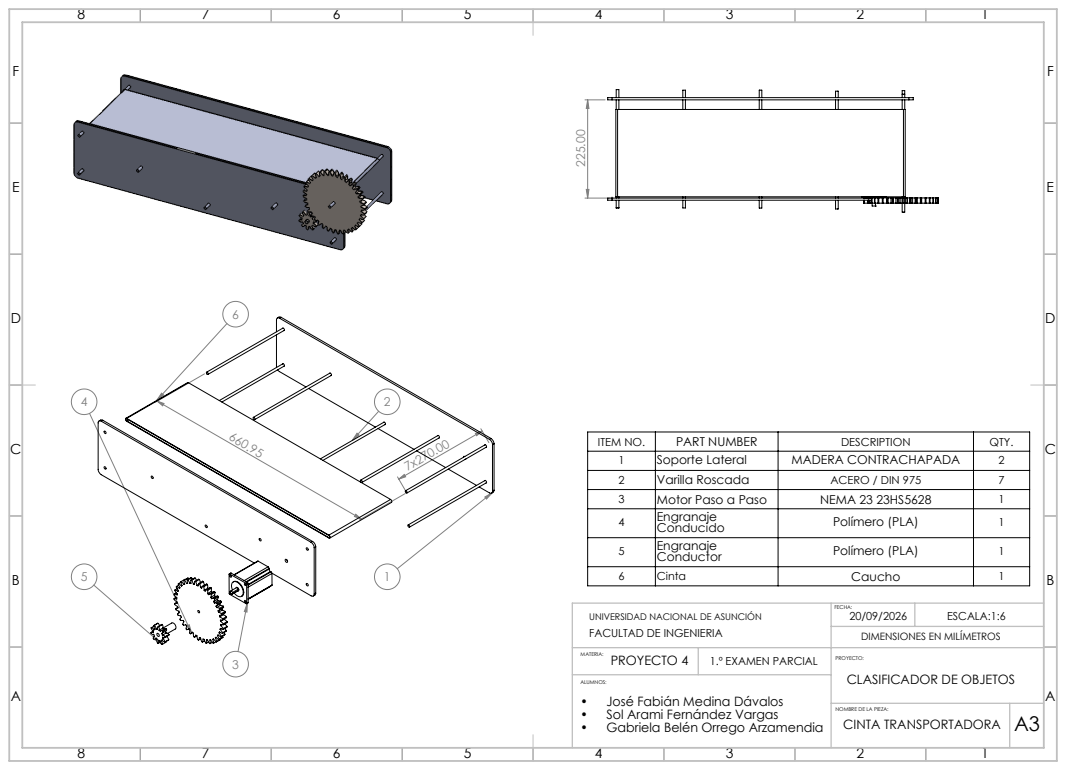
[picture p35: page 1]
1.º EXAMEN PARCIAL; DIMENSIONES EN MILÍMETROS

ITEM NO. | PART NUMBER | DESCRIPTION | QTY.
1 | Soporte Lateral | MADERA CONTRACHAPADA | 2
2 | Varilla Roscada | ACERO / DIN 975 | 7
3 | Motor Paso a Paso | NEMA 23 23HS5628 | 1
4 | Engranaje Conducido | Polímero (PLA) | 1
5 | Engranaje Conductor | Polímero (PLA) | 1

6 | Cinta | Caucho | 1

UNIVERSIDAD NACIONAL DE ASUNCIÓN
FACULTAD DE INGENIERIA
PROYECTO 4

PROYECTO:
CLASIFICADOR DE OBJETOS

ALUMNOS:
• José Fabián Medina Dávalos
• Sol Arami Fernández Vargas • Gabriela Belén Orrego Arzamendia

NOMBRE DE LA PIEZA:
CINTA TRANSPORTADORA

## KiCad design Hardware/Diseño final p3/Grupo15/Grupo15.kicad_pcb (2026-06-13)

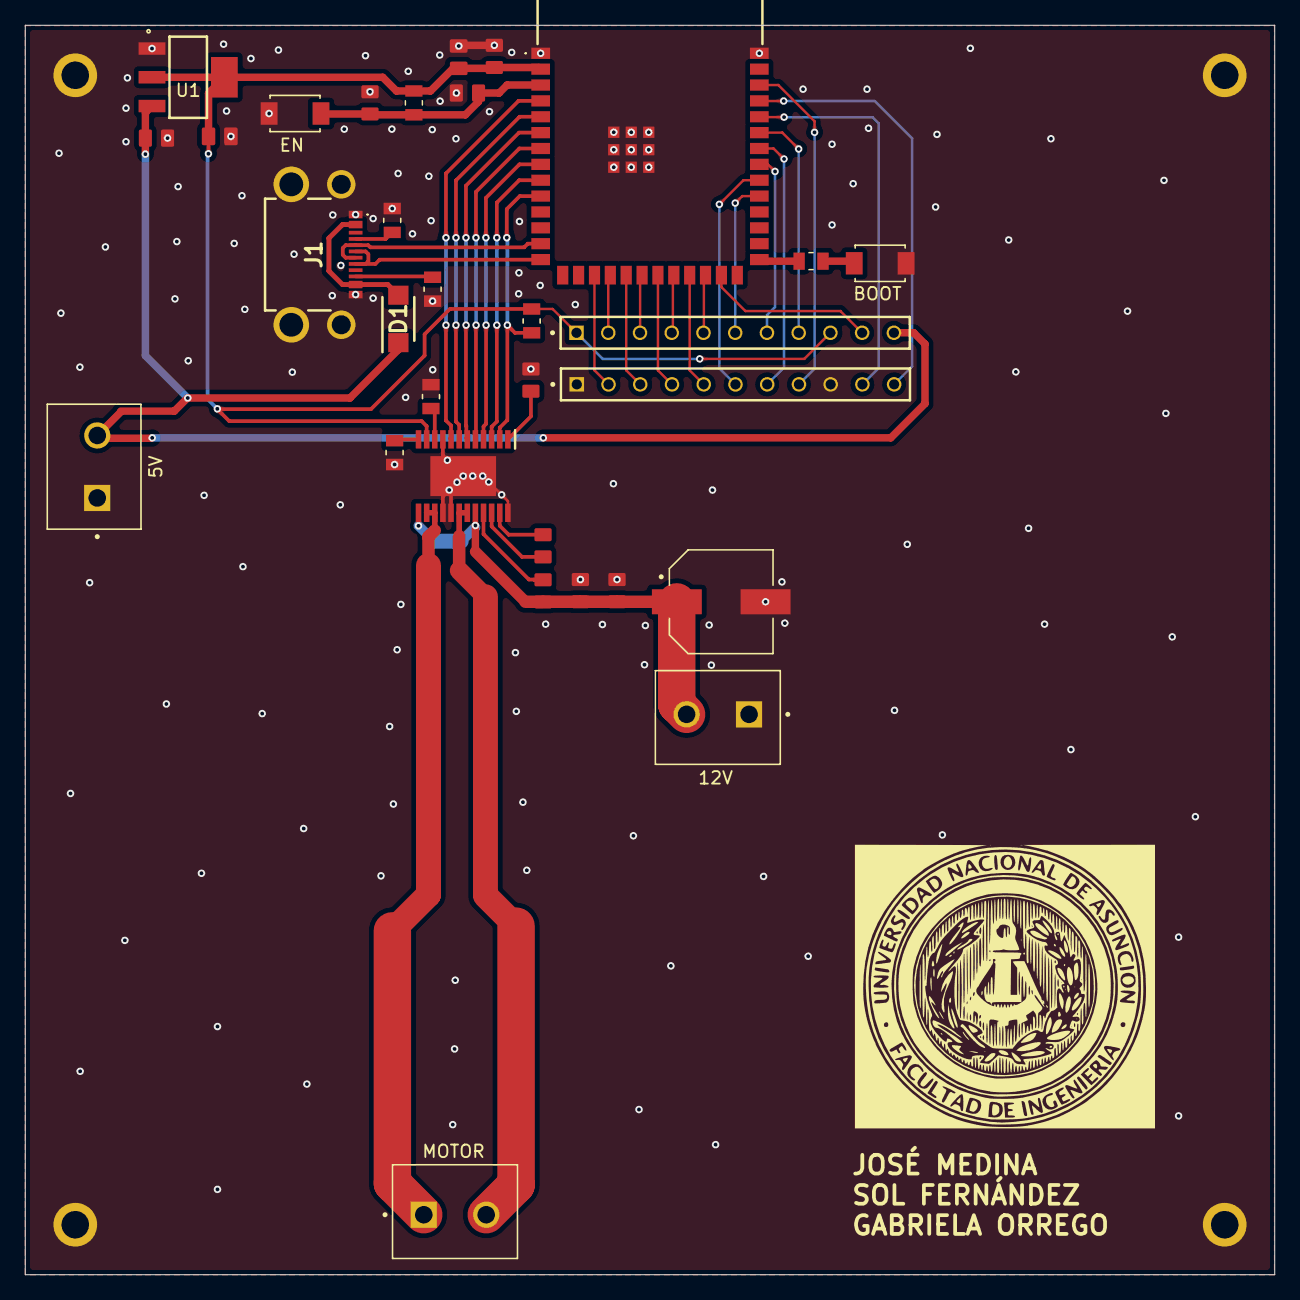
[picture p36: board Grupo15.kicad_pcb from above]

Board: 2 copper layers, 100.0 x 100.0 mm, 35 parts (0 on the bottom side), 44 nets.

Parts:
5V, 12V: KF301-2P; HANDSON_KF301-2P
BOOT: TS-1088-AR02016; SW_TS-1088-AR02016
C1, C3, C4, C10, C11: CL21B104KBCNNNC; CAPC2012X95N
C2: CL21B106KOQNNNE; CAPC2012X140N
C5: CL21A226MQQNNNE; CAPC2012X140N
C6, C7, C9: CL21B105KAFNNNE; CAPC2012X135N
C8: CL21B473KBCNNNC; CAPC2012X95N
C12: EEEFK1H101P; CAP_EEEFK1H101P
D1: SS14F-HF; SODFL4626X120N
EN: TS-1088-AR02016; SW_TS-1088-AR02016
H1, H2, H3, H4: MountingHole_2.2mm_M2_ISO7380_Pad
H1#2: DRV8873SPWPRQ1; SOP65P640X120-25N
IC1: ESP32-S3-WROOM-1-N16R8; ESP32S3WROOM1N16R8
J1: USB4510-03-1-A; USB4510031A
J5, J6: TS-111-T-A-1; SAMTEC_TS-111-T-A-1
MOTOR: KF301-2P; HANDSON_KF301-2P
R1: RC0805FR-07100RL; RESC2012X60N
R2, R5: RC0805FR-0710KL; RESC2012X60N
R3, R4: RC0805FR-075K1L; RESC2012X60N
R6, R7: RC0805FR-071K5L; RESC2012X60N
U1: LD1117S33TR; SOT230P700X180-4N

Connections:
+3V3: C2.1, C4.1, C5.1, H1#2.11 (NSLEEP), IC1.2 (3V3), J5.01, J5.09, R2.2, R5.1, U1.2 (OUT), U1.4 (OUT)
+5V: 5V.2, C1.1, D1.1 (K), J5.11, U1.3 (IN)
BOOT: IC1.27 (IO0), R1.1
D2: IC1.38 (IO2), J6.08
D3: IC1.35 (IO42), J5.08
D4: IC1.34 (IO41), J6.07
D5: IC1.33 (IO40), J5.07
D6: IC1.32 (IO39), J6.06
D7: IC1.31 (IO38), J5.06
D8: IC1.23 (IO21), J6.05
D9: IC1.24 (IO47), J5.05
EN: C3.1, C6.1, EN.1, IC1.3 (EN), R2.1
GND: 5V.1, 12V.1, BOOT.2, C1.2, C2.2, C3.2, C4.2, C5.2, C6.2, C7.1, C10.2, C11.2, C12.2, EN.2, H1.1, H1#2.9 (DISABLE), H1#2.16 (SRC_1), H1#2.17 (SRC_2), H1#2.24 (GND), H1#2.25 (EP), H2.1, H3.1, H4.1, IC1.1 (GND_1), IC1.40 (GND_2), IC1.41 (GND_3), IC1.42 (GND_4), IC1.43 (GND_5), IC1.44 (GND_6), IC1.45 (GND_7), IC1.46 (GND_8), IC1.47 (GND_9), IC1.48 (GND_10), IC1.49 (GND_11), J1.A1 (GND_1), J1.A12 (GND_2), J1.MH1, J1.MH2, J1.MH3, J1.MH4, J6.01, J6.09, R3.1, R4.2, R6.1, R7.1, U1.1 (GND)
GPIO-04: H1#2.8 (PH/IN2), IC1.4 (IO4)
GPIO-05: H1#2.7 (EN/IN1), IC1.5 (IO5)
GPIO-06: H1#2.6 (NSCS), IC1.6 (IO6)
GPIO-07: H1#2.5 (SCLK), IC1.7 (IO7)
GPIO-15: H1#2.4 (SDI), IC1.8 (IO15)
GPIO-16: H1#2.3 (SDO), IC1.9 (IO16)
GPIO-17: H1#2.2 (NFAULT), IC1.10 (IO17), R5.2
GPIO-48: IC1.25 (IO48), J5.10
GPIO-RX: IC1.36 (RXD0), J6.10
GPIO-TX: IC1.37 (TXD0), J6.11
HS: IC1.19 (IO11), J6.03
unnamed: D1.2 (A), J1.A4 (VBUS_1), J1.A9 (VBUS_2)
unnamed: C8.2, H1#2.22 (CPH)
unnamed: C8.1, H1#2.23 (CPL)
unnamed: C7.2, H1#2.1 (DVDD)
unnamed: H1#2.10 (IPROPI1), R6.2
unnamed: H1#2.12 (IPROPI2), R7.2
unnamed: C9.1, H1#2.21 (VCP)
unnamed: J1.A5 (CC1), R3.2
unnamed: J1.B5 (CC2), R4.1
unnamed: BOOT.1, R1.2
O1: H1#2.18 (OUT1_1), H1#2.19 (OUT1_2), MOTOR.2
O2: H1#2.14 (OUT2_1), H1#2.15 (OUT2_2), MOTOR.1
PC: IC1.22 (IO14), J5.04
SCL: IC1.18 (IO10), J5.02
SDA: IC1.17 (IO9), J6.02
USB_D+: IC1.14 (IO20), J1.A6 (DP1), J1.B6 (DP2)
USB_D-: IC1.13 (IO19), J1.A7 (DN1), J1.B7 (DN2)
VM: 12V.2, C9.2, C10.1, C11.1, C12.1, H1#2.13 (VM_1), H1#2.20 (VM_2)
VS: IC1.20 (IO12), J5.03
XC: IC1.21 (IO13), J6.04

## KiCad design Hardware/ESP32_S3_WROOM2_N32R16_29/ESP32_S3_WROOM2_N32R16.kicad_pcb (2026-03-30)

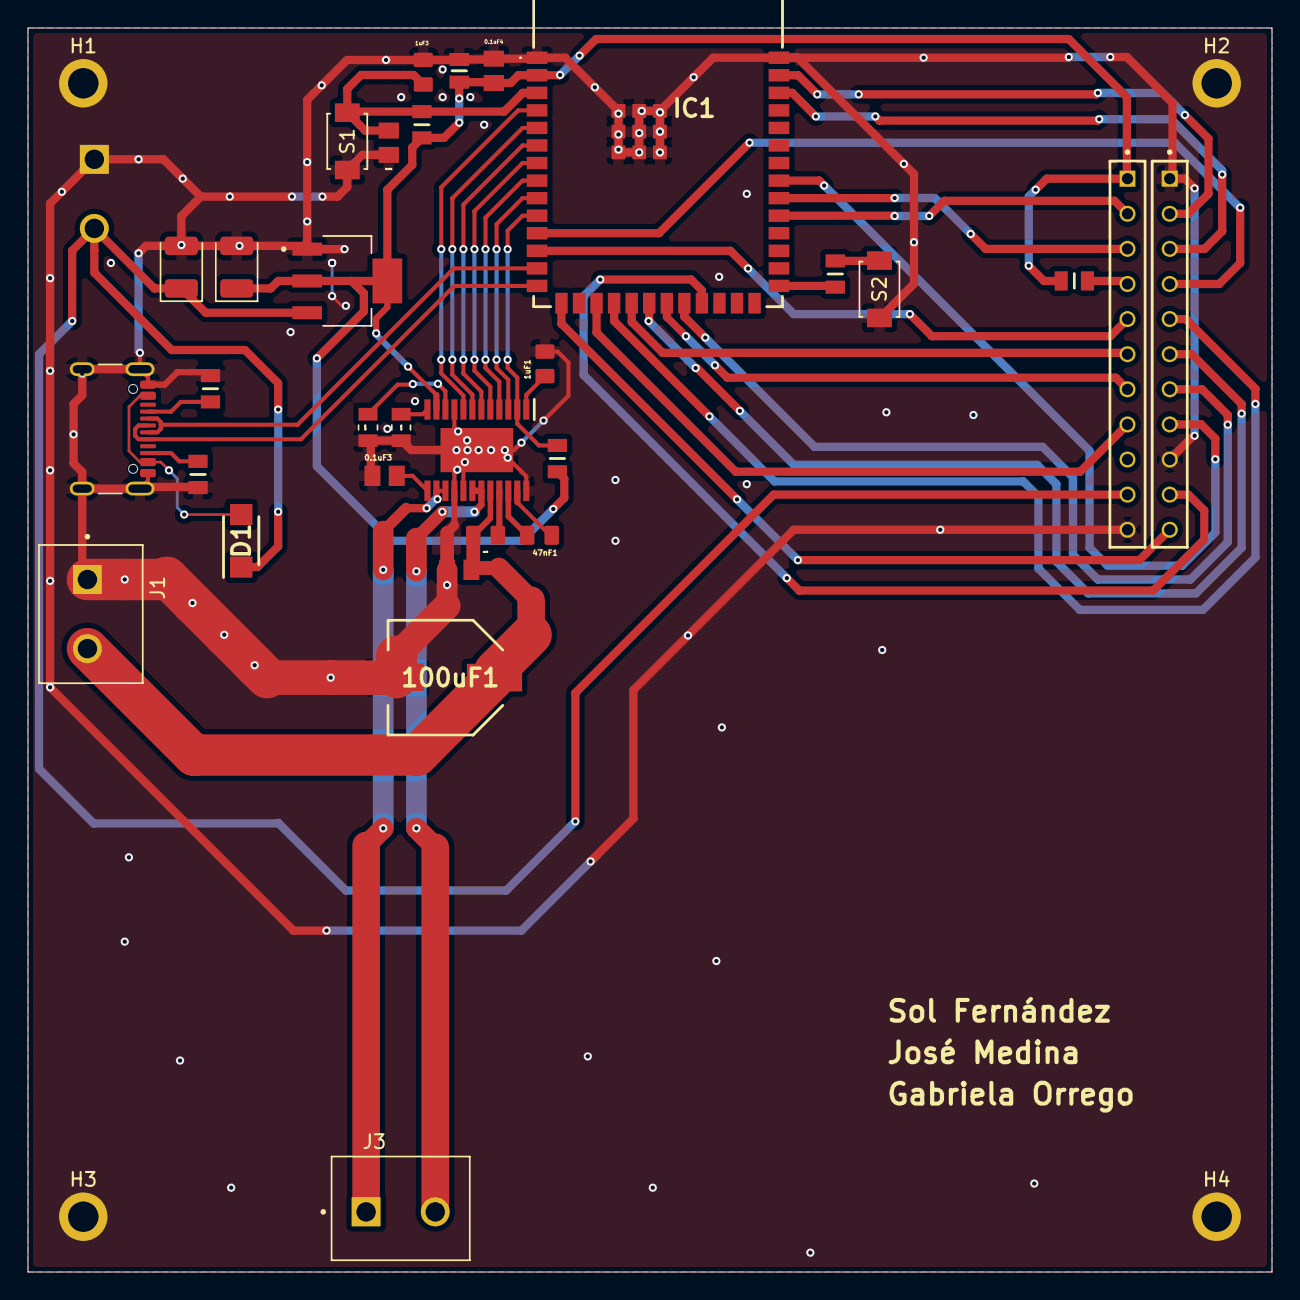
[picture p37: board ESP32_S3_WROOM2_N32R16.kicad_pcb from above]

Board: 2 copper layers, 90.0 x 90.0 mm, 36 parts (1 on the bottom side), 44 nets.

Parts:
0.1k1: RC0805FR-07100RL; RESC2012X60N
0.1uF1, 0.1uF2, 0.1uF3, 0.1uF4: 08055C104KAT2A; CAPC2012X94N
1.5k1, 1.5k2: RC0805FR-071K5L; RESC2012X60N
1uF1, 1uF2, 1uF3: CL21B105KAFNNNE; CAPC2012X135N
5.1k1, 5.1k2: RK73H2ATTD5101F; RESC2012X60N
10k1, 10k2, 10k3: RC0805FR-0710KL; RESC2012X60N
22uF1: CL21A226MQQNNNE; CAPC2012X140N
47nF1: CL21B473KBCNNNC; CAPC2012X95N
100uF1: EEE-FK1H101P; EEHZT1E331UP
C1, C2: 10uF; CP_EIA-3528-21_Kemet-B
D1: SS14F-HF; SODFL4626X120N
H1, H2, H3, H4: MountingHole_2.2mm_M2_ISO7380_Pad
H1#2: DRV8873SPWPRQ1; SOP65P640X120-25N
IC1: ESP32-S3-WROOM-2-N32R16V; ESP32S3WROOM2N32R16V
J1, J2, J3: KF301-2P; HANDSON_KF301-2P
J4, J5: TS-111-T-A-1; SAMTEC_TS-111-T-A-1
S1, S2: TS-1088-AR02016; SW_TS-1088-AR02016
USB1: USB_C_Receptacle_USB2.0_16P; USB_C_Receptacle_GCT_USB4105-xx-A_16P_TopMnt_Horizontal
VR1: LM1117MPX-3.3_NOPB; VREG_LM1117MPX-3.3_NOPB

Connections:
+3V3: 0.1uF4.2, 10k1.2, 10k2.2, 10k3.2, 22uF1.2, C2.1, H1#2.11 (NSLEEP), IC1.2 (3V3), J5.01, VR1.2 (VOUT_2), VR1.4 (VOUT_4)
+5V: C1.1, D1.1 (K), J2.2, J5.10, VR1.3 (VIN)
BOOT: 0.1k1.1, IC1.27 (IO0)
D+: IC1.14 (IO20), USB1.A6 (D+), USB1.B6 (D+)
D-: IC1.13 (IO19), USB1.A7 (D-), USB1.B7 (D-)
EN: 0.1uF1.1, 1uF3.2, 10k2.1, IC1.3 (EN), S1.1
GND: 0.1uF1.2, 0.1uF2.1, 0.1uF3.1, 0.1uF4.1, 1.5k1.1, 1.5k2.1, 1uF1.2, 1uF3.1, 5.1k1.2, 5.1k2.2, 22uF1.1, 100uF1.2 (-), C1.2, C2.2, H1.1, H1#2.9 (DISABLE), H1#2.16 (SRC_1), H1#2.17 (SRC_2), H1#2.24 (GND), H1#2.25 (EP), H2.2, H3.3, H4.4, IC1.1 (GND_1), IC1.40 (GND_2), IC1.41 (GND_3), IC1.42 (GND_4), IC1.43 (GND_5), IC1.44 (GND_6), IC1.45 (GND_7), IC1.46 (GND_8), IC1.47 (GND_9), IC1.48 (GND_10), IC1.49 (GND_11), J1.1, J2.1, J4.01, J4.09, J5.11, S1.2, S2.2, USB1.A1 (GND), USB1.A12 (GND), USB1.B1 (GND), USB1.B12 (GND), USB1.SH (SHIELD), VR1.1 (GND)
GPIO01: IC1.39 (IO1), J4.02
GPIO02: IC1.38 (IO2), J4.03
GPIO03: IC1.15 (IO3), J4.11
GPIO04: H1#2.8 (PH/IN2), IC1.4 (IO4)
GPIO05: H1#2.7 (EN/IN1), IC1.5 (IO5)
GPIO06: H1#2.6 (NSCS), IC1.6 (IO6)
GPIO07: H1#2.5 (SCLK), IC1.7 (IO7)
GPIO08: IC1.12 (IO8), J5.05
GPIO09: IC1.17 (IO9), J5.08
GPIO10: IC1.18 (IO10), J4.05
GPIO11: IC1.19 (IO11), J5.06
GPIO12: IC1.20 (IO12), J4.06
GPIO13: IC1.21 (IO13), J5.07
GPIO14: IC1.22 (IO14), J4.07
GPIO15: H1#2.4 (SDI), IC1.8 (IO15)
GPIO16: H1#2.3 (SDO), IC1.9 (IO16)
GPIO17: 10k1.1, H1#2.2 (NFAULT), IC1.10 (IO17)
GPIO18: IC1.11 (IO18), J4.04
GPIO21: IC1.23 (IO21), J4.10
GPIO38: IC1.31 (IO38), J5.02
GPIO39: IC1.32 (IO39), J5.03
GPIO40: IC1.33 (IO40), J4.08
unnamed: 0.1k1.2, S2.1
unnamed: 10k3.1, J5.04
unnamed: D1.2 (A), USB1.A4 (VBUS), USB1.A9 (VBUS), USB1.B4 (VBUS), USB1.B9 (VBUS)
unnamed: 47nF1.2, H1#2.22 (CPH)
unnamed: 47nF1.1, H1#2.23 (CPL)
unnamed: 1uF1.1, H1#2.1 (DVDD)
unnamed: 1.5k2.2, H1#2.10 (IPROPI1)
unnamed: 1.5k1.2, H1#2.12 (IPROPI2)
unnamed: 1uF2.2, H1#2.21 (VCP)
unnamed: 0.1uF3.2, H1#2.13 (VM_1)
unnamed: 5.1k2.1, USB1.A5 (CC1)
unnamed: 5.1k1.1, USB1.B5 (CC2)
O1: H1#2.18 (OUT1_1), H1#2.19 (OUT1_2), J3.2
O2: H1#2.14 (OUT2_1), H1#2.15 (OUT2_2), J3.1
VM: 0.1uF2.2, 1uF2.1, 100uF1.1 (+), H1#2.20 (VM_2), J1.2

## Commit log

2026-03-30 Placa pcb
    [ESP32_S3_WROOM2_N32R16.kicad_pcb, ESP32_S3_WROOM2_N32R16.kicad_sch]
2026-06-01 Revise README with current project status and details
    Updated project status, description, and hardware architecture details.
2026-06-01 Create Clasificador de objetos.pdf
2026-06-01 Update README with server details and process flow
2026-06-01 Update next steps in README
    Removed the communication step for the ESP32-S3 from the next steps section.
2026-06-13 Implement complete system with camera and motor control
    Updated the complete system to include camera, webhook, IR sensor, DC motor, and servo functionalities.
2026-06-13 Actualización Examen Final
    [08055C104KAT2A.step, CL21A226MQQNNNE.step, CL21A226MQQNNNE.stp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]
2026-06-15 Prueba de funcionamiento
2026-06-15 error de subida
2026-06-15 evidencia de funcionamiento
2026-08-04 Agrega diagrama de Gantt y snapshot de app de monitoreo
    [Cronograma de actividades.xlsx]
2026-08-25 feat(p4): update Gantt chart legibility and integrate Machine Design LAB mechanical design
    [Geneva_Mechanism.SLDASM, Geneva_wheel^Geneva_Mechanism.SLDPRT, Transmission_assembly.SLDASM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]
2026-09-21 docs(p4): actualizar documentacion, planos y diseno mecanico para el 1er parcial
    [BOM.csv, Cinta.SLDPRT, Engranaje_C.SLDPRT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]

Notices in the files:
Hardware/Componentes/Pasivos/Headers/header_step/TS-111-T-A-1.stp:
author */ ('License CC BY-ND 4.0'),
